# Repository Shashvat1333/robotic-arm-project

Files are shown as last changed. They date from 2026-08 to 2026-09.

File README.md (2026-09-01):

# Robotic Arm Project

A custom-designed, multi-axis robotic arm controlled wirelessly via Bluetooth using an ESP32 and Bluepad32.

Robotic Arm Render

## Table of Contents
- [Overview](#overview)
- [Repository Structure](#repository-structure)
- [CAD Model & Assembly](#cad-model--assembly)
- [Schematic & Wiring](#schematic--wiring)
- [Firmware](#firmware)
- [Getting Started](#getting-started)
- [Bill of Materials (BOM)](#bill-of-materials-bom)
- [License](#license)

## Overview
This project combines mechanical engineering, 3D printing, electronics design, and embedded firmware development into a cohesive hardware system. The primary goal is to build a fully articulated, functional robotic arm with multiple degrees of freedom that responds seamlessly to a wireless game controller. By integrating custom gear assemblies, iterative 3D-printed brackets, and robust power management, this project bridges the gap between digital design and physical prototyping.

Building a robotic arm from scratch meant handling every stage of development personally. From sketching the initial motion paths to balancing structural weight limits against servo torque ratings, every choice was made to keep the system sturdy yet responsive. Instead of relying on pre-made kits, the entire assembly was built up component by component to ensure it could handle real physical loads without flexing or slipping at the joints.

### Key Features:
- **Custom Mechanical Design:** Engineered with precise tolerance margins for 3D printing, featuring custom gear trains and linkage assemblies designed in Onshape.
- **Wireless Control Integration:** Utilizes an ESP32 microcontroller paired with the Bluepad32 framework to read live joystick and button inputs from a standard Bluetooth controller.
- **Safe Power Distribution:** Employs a dedicated 5V 10A DC power supply routed through custom soldered bus lines on a perfboard, replacing high-resistance plastic breadboards to handle heavy servo current draws safely.

---

## Repository Structure

```
robotic-arm-project/
├── CAD/                   # .step files for all printed/machined parts
├── Firmware/               # ESP32 firmware (FIRMWARE.ino)
├── Wiring Diagrams.md      # Full wiring/schematic reference
├── Images & Demo/          # Renders, build photos, demo video
├── BOM.md                  # Full bill of materials
├── JOURNAL.md              # Build log / engineering journal
├── LICENSE.md
└── README.md
```

---

## CAD Model & Assembly
The structural framework and mechanical joints of the robotic arm were modeled with close attention to mechanical clearances and structural integrity. Designing the parts in Onshape allowed for careful testing of gear ratios, pivot points, and clearance gaps so the 3D-printed pieces fit together smoothly with minimal post-processing. To support open-source collaboration and manufacturing, all production-ready parts and full assemblies are stored directly in the [CAD](https://github.com/Shashvat1333/robotic-arm-project/tree/main/CAD) folder as `.step` files.

When putting the physical frame together, thermal-set inserts were melted directly into the plastic structures using a soldering iron, giving the M3 bolts a solid metal thread to bite into. This prevents the plastic from stripping out under regular movement and makes it easy to take joints apart for maintenance or upgrades.

https://github.com/user-attachments/assets/6f530a01-1f68-40d2-a437-52708d4fa79e

---

## Schematic & Wiring
Because this project utilizes modular components wired together on a custom soldered perfboard rather than a manufactured printed circuit board, the system relies on a detailed wiring layout. High-torque servos pull significant current under load, which is why standard breadboards were abandoned early on to prevent melting rails or voltage drops.

Instead, a custom perfboard layout uses heavy solder traces to act as main power and ground distribution rails, ensuring every servo gets clean, steady voltage directly from the 10-amp adapter. You can view the complete connection specifications and documentation in [Wiring Diagrams.md](Wiring%20Diagrams.md).

| Component | ESP32 GPIO (Signal) | Power (+) | Ground (–) |
|---|---|---|---|
| Servo 1 – Base (DS3225MG) | GPIO 13 | Perfboard + bus line | Perfboard – bus line |
| Servo 2 – Shoulder (DS3225MG) | GPIO 12 | Perfboard + bus line | Perfboard – bus line |
| Servo 3 – Elbow (DS3225MG) | GPIO 14 | Perfboard + bus line | Perfboard – bus line |
| Servo 4 – Wrist Pitch (DS3225MG) | GPIO 27 | Perfboard + bus line | Perfboard – bus line |
| Servo 5 – Wrist Roll (MG90S) | GPIO 26 | Perfboard + bus line | Perfboard – bus line |
| Servo 6 – Gripper (MG90S) | GPIO 25 | Perfboard + bus line | Perfboard – bus line |
| ESP32 NodeMCU Board | — | VIN pin connected to + bus | GND pin connected to – bus |
| Power Supply | — | 5V 10A DC Adapter (+) | 5V 10A DC Adapter (–) |

---

## Firmware
The control firmware is written in C++ using the Arduino framework, integrating the `ESP32Servo` and `Bluepad32` libraries to map controller joysticks and triggers directly to servo positions. The program continuously listens for a paired Bluetooth gamepad, reads the analog stick coordinates, and translates those inputs into precise PWM signals for each servo motor.

- **Source code:** [FIRMWARE.ino](https://github.com/Shashvat1333/robotic-arm-project/blob/main/FIRMWARE.ino)
- **Required libraries:** `ESP32Servo`, `Bluepad32`
- **Board:** ESP32 Dev Module

---

## Getting Started

To build and run this project yourself:

1. **Print the parts** — Slice the `.step` files from the [CAD](https://github.com/Shashvat1333/robotic-arm-project/tree/main/CAD) folder (built and tested using PLA+ filament).
2. **Assemble the frame** — Install M3 heat-set inserts into the printed parts using a soldering iron, then bolt the assembly together following the CAD model.
3. **Wire the electronics** — Follow [Wiring Diagrams.md](Wiring%20Diagrams.md) to connect servos, the ESP32, and the power supply through the perfboard bus lines.
4. **Flash the firmware** — Open [FIRMWARE.ino](https://github.com/Shashvat1333/robotic-arm-project/blob/main/FIRMWARE.ino) in the Arduino IDE, install the `ESP32Servo` and `Bluepad32` libraries, select the **ESP32 Dev Module** board, and upload.
5. **Pair a controller** — Power on the arm and pair a Bluetooth gamepad. The arm will respond to joystick and button input once connected.

---

## Bill of Materials (BOM)

| # | Item | Qty | Description | Price (tax incl.) | Link |
|---|---|-----|---|---|---|
| 1 | 25KG Digital RC Servo (DS3225) | 4 Pack | Waterproof, high-torque servo for main arm joints | $65.60 | [AliExpress](https://www.aliexpress.com/item/1005009734701047.html) |
| 2 | MG90S 9g Micro Servo Motor | 2 Pack | Small servo for gripper / wrist actuation | $7.40 | [AliExpress](https://www.aliexpress.com/item/4000903254039.html) |
| 3 | 5V 10A Power Supply Adapter | 1 | Main power supply for servos | $23.40 | [AliExpress](https://www.aliexpress.com/item/1005004121728138.html) |
| 4 | 5.5x2.1mm DC Power Female Jack Pigtail | 1 | Connects power adapter to circuit | $6.00 | [AliExpress](https://www.aliexpress.com/item/1005008401380227.html) |
| 5 | ESP32-WROOM-32 Dev Board (CH340C, Type-C) | 1 | Dual-core WiFi + Bluetooth MCU for arm control (Bluepad32) | $8.00 | [AliExpress](https://www.aliexpress.com/item/1005008981904299.html) |
| 6 | 22AWG Stranded Wire | 1 | Flexible wiring for all connections, including servo leads | $10.17 | [AliExpress](https://www.aliexpress.com/item/1005006441248773.html) |
| 7 | KADRICK 420PCS M3 Heat Set Inserts Kit | 1 | Threaded inserts for 3D-printed parts | $25.48 | [Amazon](https://www.amazon.com/Threaded-Assortment-M3x6-30mm-Installation-Printing/dp/B0GYRQG7F2/) |
| 8 | Perfboard (6cm × 8cm) | 1 | Solder-based board — replaces breadboard for safe high-current servo wiring | $2.80 | [AliExpress](https://www.aliexpress.com/item/1005006829112244.html) |
| 9 | PLA+ Filament 1.75mm 1KG | 673g used | 3D printing material for arm structural parts — cost reflects grams actually used (sliced in PrusaSlicer), not full spool purchased | $15.07 | [AliExpress](https://www.aliexpress.com/item/1005011683191901.html) |
| 10 | Import Charges | — | Customs/import fees on international orders | $12.00 | — |

**Total Project Cost: $175.92**

Full breakdown also available in [BOM.md](https://github.com/Shashvat1333/robotic-arm-project/blob/main/BOM.md).

---

## License

This project is licensed under the terms specified in [LICENSE.md](https://github.com/Shashvat1333/robotic-arm-project/blob/main/LICENSE.md).

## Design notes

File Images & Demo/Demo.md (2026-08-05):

Robotic Arm Project DEMOs
-------------------------------------------------------------------------------------------------------------------------------------------------------------------

https://github.com/user-attachments/assets/6f530a01-1f68-40d2-a437-52708d4fa79e

-------------------------------------------------------------------------------------------------------------------------------------------------------------------

Main Arm

-------------------------------------------------------------------------------------------------------------------------------------------------------------------

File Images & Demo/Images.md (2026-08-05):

Robotic Arm Project Images
-------------------------------------------------------------------------------------------------------------------------------------------------------------------



-------------------------------------------------------------------------------------------------------------------------------------------------------------------



-------------------------------------------------------------------------------------------------------------------------------------------------------------------



-------------------------------------------------------------------------------------------------------------------------------------------------------------------



-------------------------------------------------------------------------------------------------------------------------------------------------------------------



-------------------------------------------------------------------------------------------------------------------------------------------------------------------



-------------------------------------------------------------------------------------------------------------------------------------------------------------------



-------------------------------------------------------------------------------------------------------------------------------------------------------------------



-------------------------------------------------------------------------------------------------------------------------------------------------------------------



-------------------------------------------------------------------------------------------------------------------------------------------------------------------



-------------------------------------------------------------------------------------------------------------------------------------------------------------------



-------------------------------------------------------------------------------------------------------------------------------------------------------------------

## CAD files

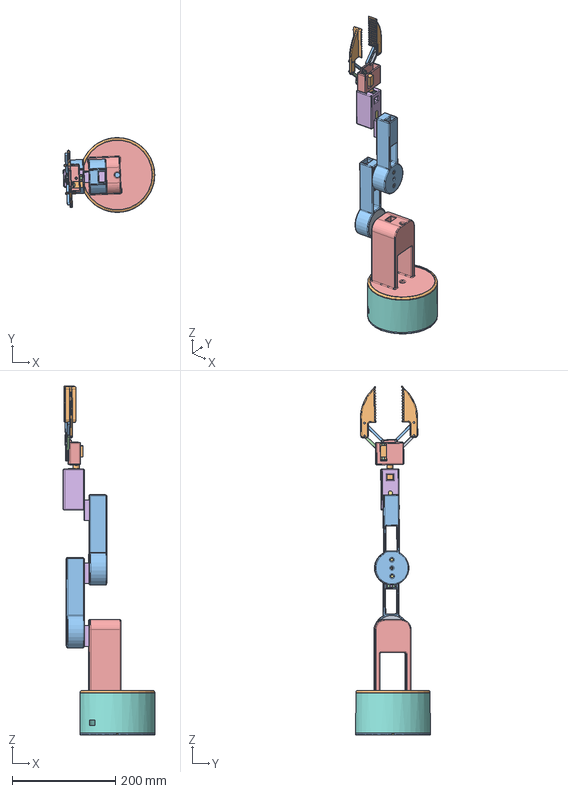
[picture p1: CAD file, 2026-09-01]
CAD/MAIN.step
177.9 x 145.4 x 676.5 mm
Spur gear (24 teeth)
Spur gear (20 teeth) x 2

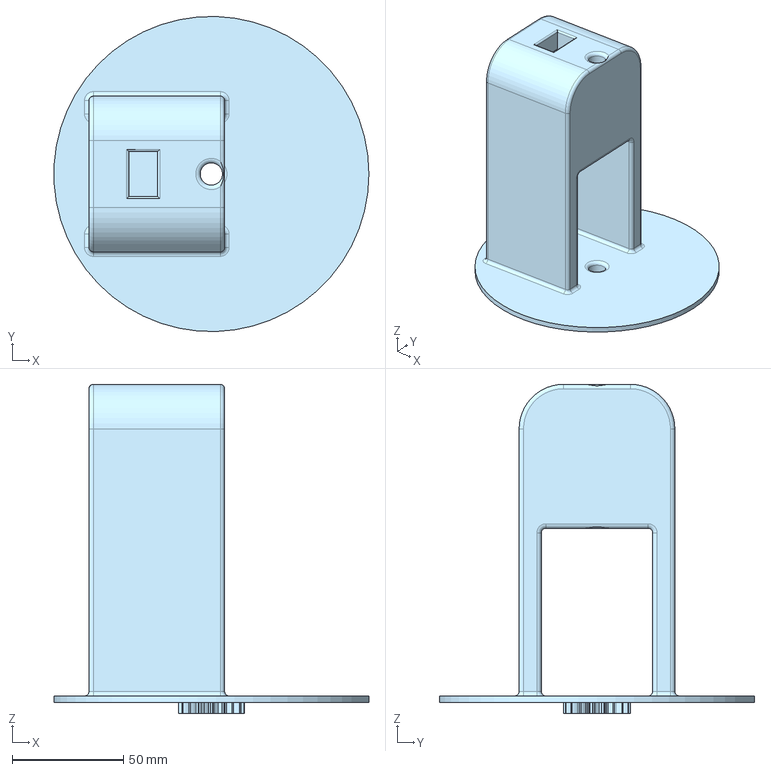
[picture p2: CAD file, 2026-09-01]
CAD/Base Top-Sholder.step
141.5 x 141.5 x 148.0 mm

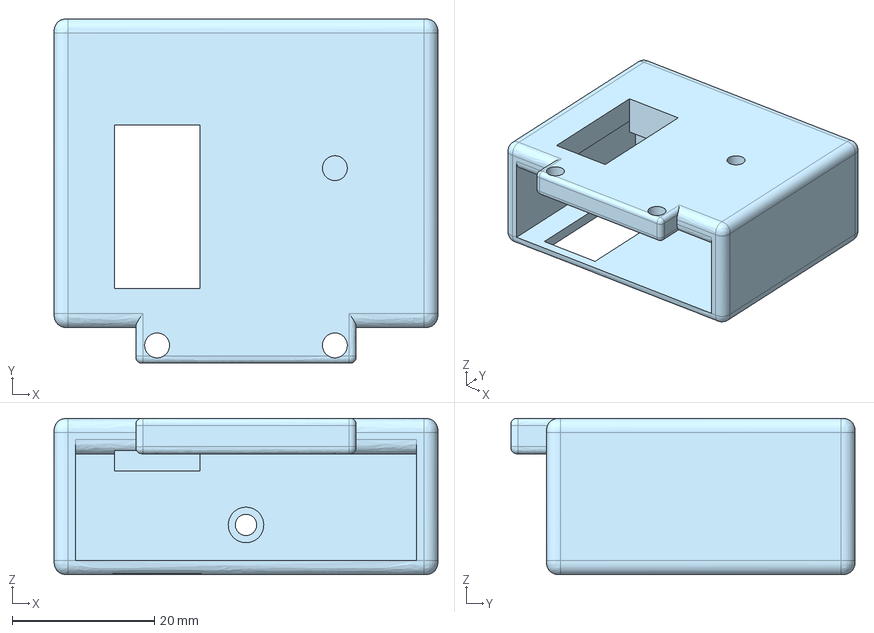
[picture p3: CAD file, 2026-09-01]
CAD/Claw Base.step
54.0 x 48.4 x 22.0 mm

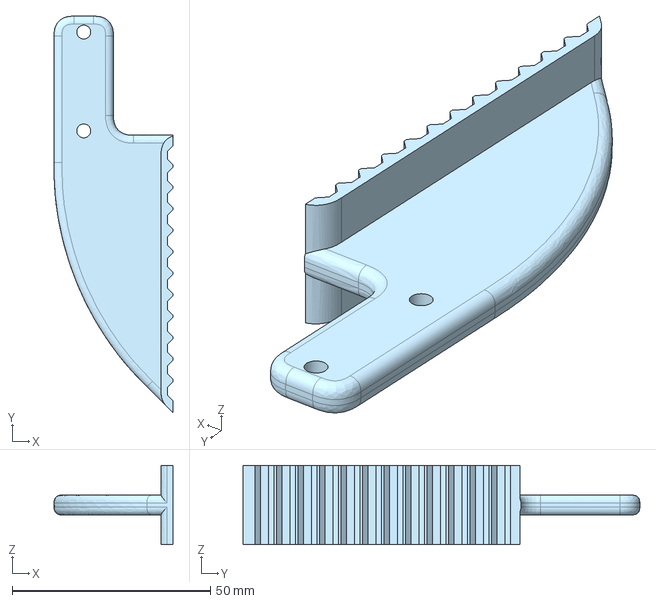
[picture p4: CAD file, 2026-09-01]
CAD/Claw x2.step
30.0 x 100.0 x 20.0 mm

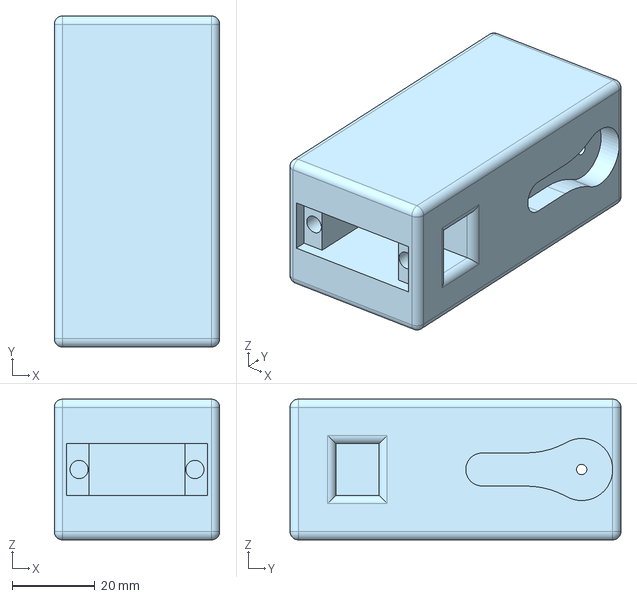
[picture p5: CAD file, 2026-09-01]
CAD/Wrist.step
40.0 x 80.0 x 34.0 mm

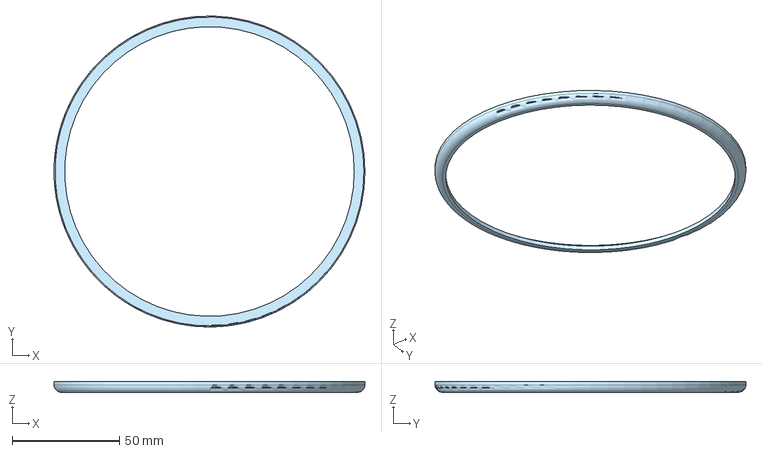
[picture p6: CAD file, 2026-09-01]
CAD/retaining ring.step
145.0 x 145.0 x 5.00 mm

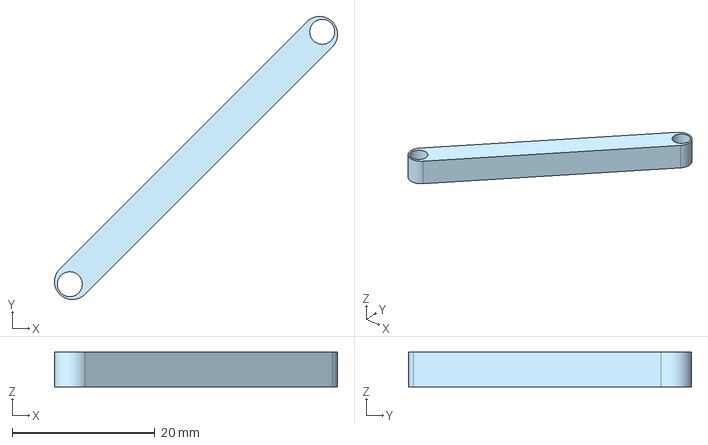
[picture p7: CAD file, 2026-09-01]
CAD/Base to Claw connector x2.step
39.6 x 39.6 x 4.90 mm

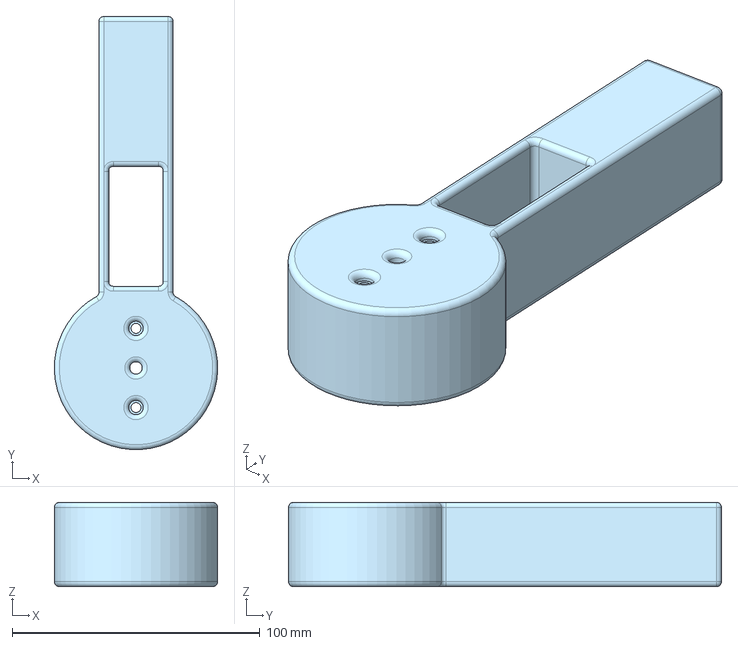
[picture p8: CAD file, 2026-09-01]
CAD/Arm x2.step
65.9 x 174.9 x 34.0 mm

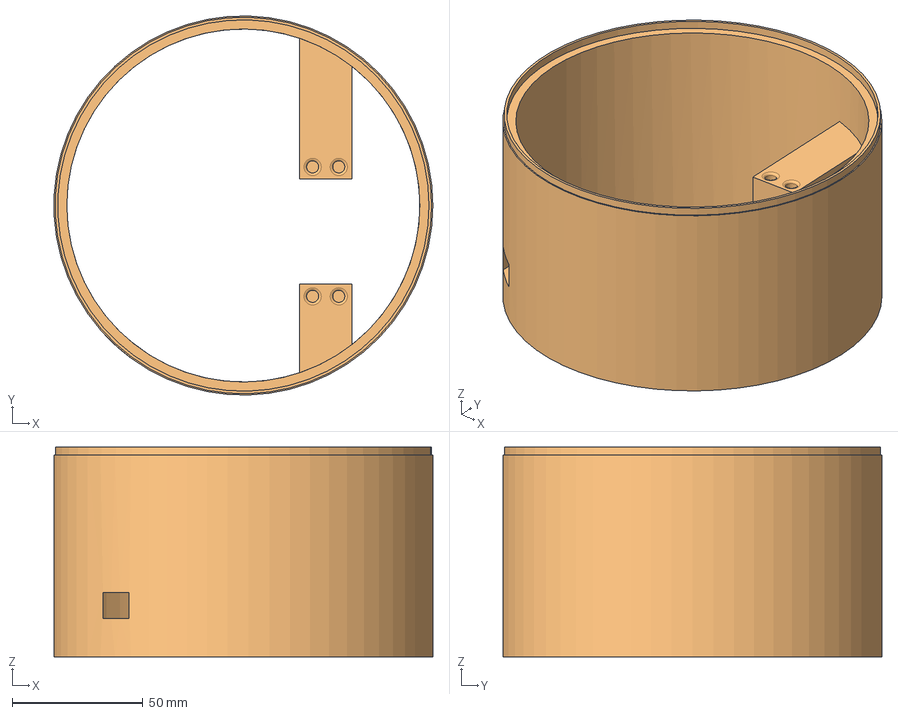
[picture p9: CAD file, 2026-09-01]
CAD/Base Body.step
144.9 x 144.9 x 80.3 mm

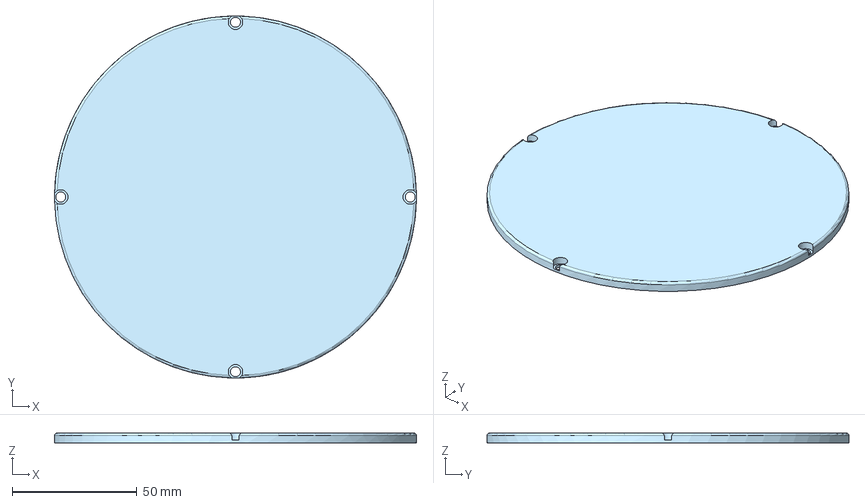
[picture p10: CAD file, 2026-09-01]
CAD/Base Bottom.step
145.0 x 145.0 x 4.00 mm

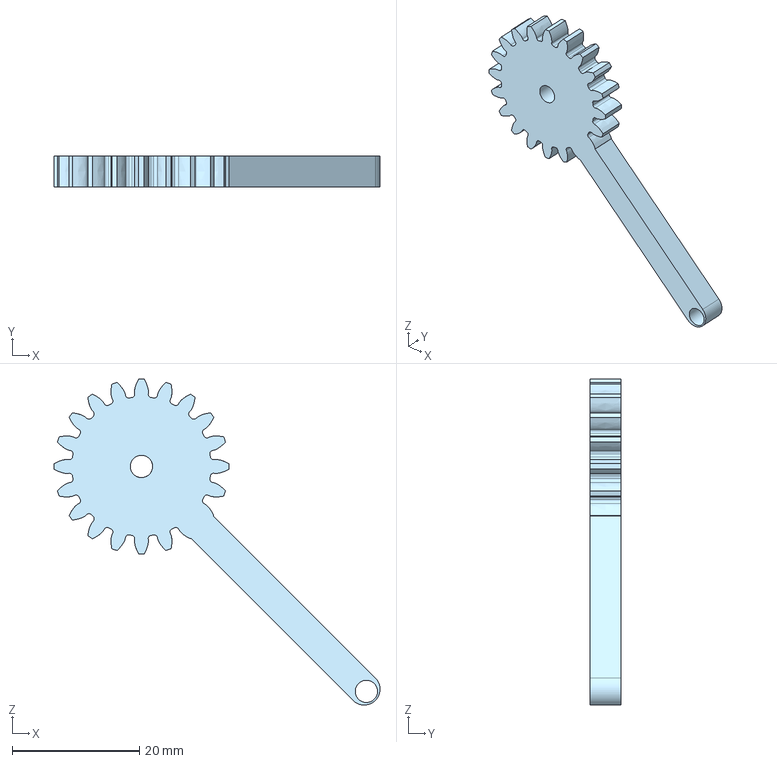
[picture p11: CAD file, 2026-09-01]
CAD/Claw Gear.step
51.2 x 4.90 x 51.2 mm

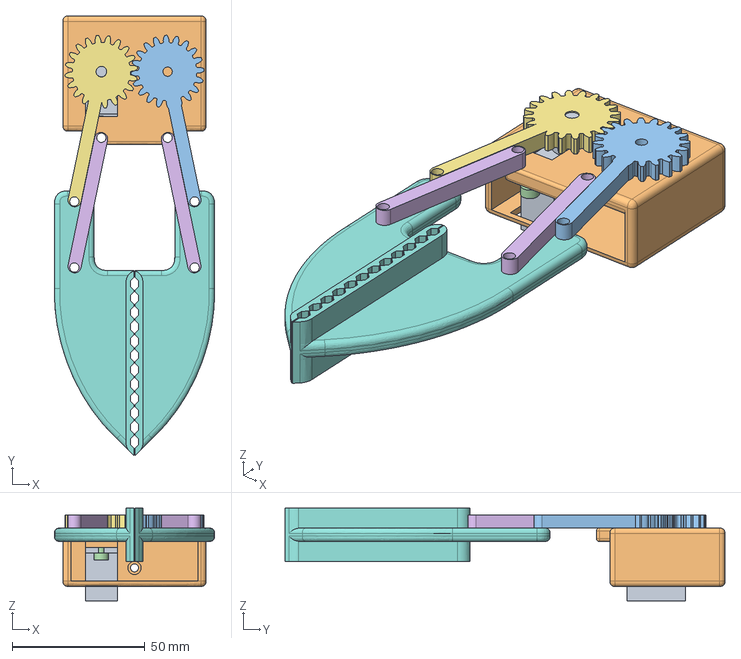
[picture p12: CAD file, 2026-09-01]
CAD/CLAW.step
60.4 x 166.0 x 34.9 mm
Spur gear (20 teeth) x 2

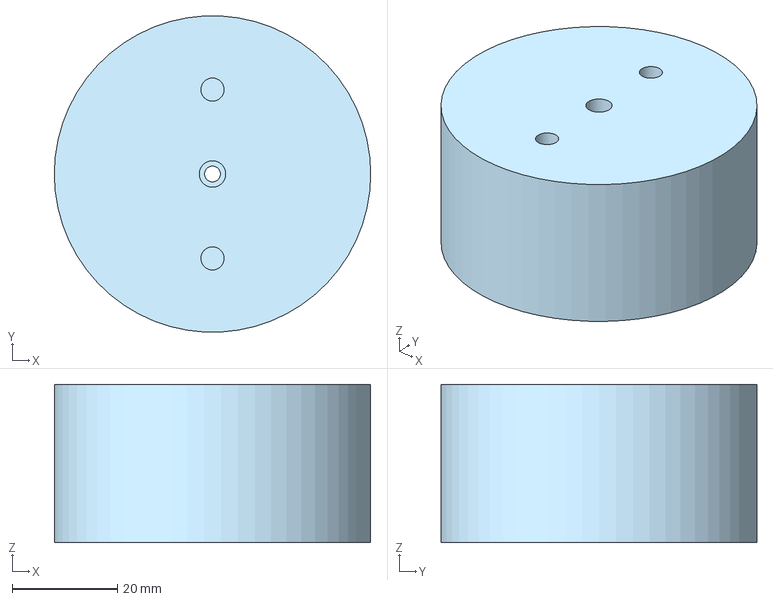
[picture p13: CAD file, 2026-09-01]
CAD/Arm-Servo Connector x2.step
60.0 x 59.9 x 30.0 mm

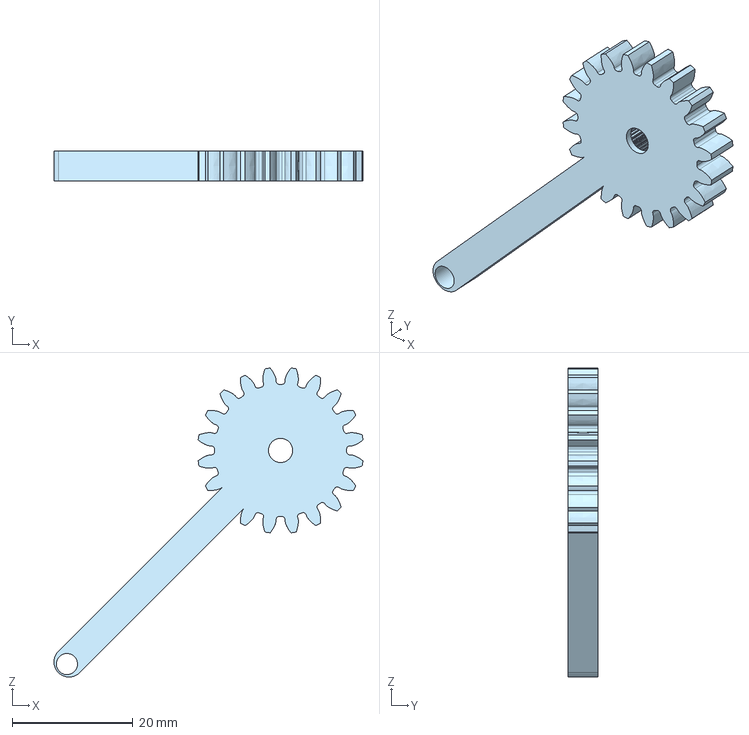
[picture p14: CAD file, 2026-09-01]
CAD/Claw Gear Servo.step
51.1 x 5.00 x 51.1 mm

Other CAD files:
CAD/Servo Gear.step

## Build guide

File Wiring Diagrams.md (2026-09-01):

**Robotics Arm Servo Wiring Diagram**
------------------------------------------------------------------------



------------------------------------------------------------------------

| Component | ESP32 GPIO (Signal) | Power (+) | Ground (–) |
| --- | --- | --- | --- |
| Servo 1 – Base (DS3225MG) | GPIO 13 | Perfboard + line | Perfboard – line |
| Servo 2 – Shoulder (DS3225MG) | GPIO 12 | Perfboard + line | Perfboard – line |
| Servo 3 – Elbow (DS3225MG) | GPIO 14 | Perfboard + line | Perfboard – line |
| Servo 4 – Wrist Pitch (DS3225MG) | GPIO 27 | Perfboard + line | Perfboard – line |
| Servo 5 – Wrist Roll (MG90S) | GPIO 26 | Perfboard + line | Perfboard – line |
| Servo 6 – Gripper (MG90S) | GPIO 25 | Perfboard + line | Perfboard – line |
| ESP32 (board power, via fuse) | — | Perfboard + line → ESP32 5V/VIN pin | Perfboard – line → ESP32 GND pin |
| Perfboard + power line | — | 5V 10A Adapter (+) | — |
| Perfboard – ground line | — | — | 5V 10A Adapter (–) |

**How it flows:** The 5V 10A DC power supply connects directly to the custom soldered vertical bus lines on the perfboard, creating solid positive and negative rails. Every servo taps its power and ground straight into these soldered tracks. The ESP32 also bridges directly to these shared rails for its supply voltage and common ground, while individual signal wires run straight from each servo to their respective ESP32 GPIO pins.

------------------------------------------------------------------------

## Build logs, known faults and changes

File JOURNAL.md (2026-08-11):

Robotic Arm Project Journal
-------------------------------------------------------------------------------------------------------------------------------------------------------------------

**Day 1**: July 11, 2026

Time spent: **2 hours**

Started planning the robotic arm today, mostly research before touching CAD. Compared 3, 4, 5, and 6 DOF designs, and I'm currently leaning toward 6 DOF since it gives more flexibility, even though it adds complexity. Looked into open-loop vs closed-loop servos and decided open-loop PWM should be fine since my payload is under 500g. Also learned torque needs go up the closer a joint is to the base, so I'm planning stronger servos like the MG996R for the base and shoulder and weaker ones like the MG90S for the wrist and gripper. Picked the ESP32 over Arduino mainly because of the built-in WiFi.
Next: build a BOM, calculate real torque numbers, start early CAD sketches.

-------------------------------------------------------------------------------------------------------------------------------------------------------------------

**Day 2**: July 12, 2026

Time spent: **2.5 hours**

Ran actual torque numbers today. With a 42cm arm and 100g payload, the shoulder needs about 15.4 kg cm of torque, which is more than a standard MG996R can handle comfortably. Switched the base and shoulder servos to the DS3230MG since it gives a lot more headroom. Updated my planned lineup to two DS3230MG for base and shoulder, two MG996R for elbow and wrist pitch, and two MG90S for wrist roll and gripper. Also bumped my power supply up to 5V 10A after realizing worst-case current draw could hit 9 to 13A.
Next: finish the BOM, design brackets for the heat set inserts, check clearances before printing anything.

-------------------------------------------------------------------------------------------------------------------------------------------------------------------

**Day 3**: July 13, 2026

Time spent: **4 hours 30 minutes**

Started actual CAD today, focused mostly on the base gear system. I wanted full 360 rotation out of a 270-degree servo instead of adding a slip ring, and worked out that a 3 to 4 step up gear ratio would do it. My first gear sizes were too small, and the teeth interfered with each other, so I bumped them up to 18 and 24 teeth using the same ratio, and that fixed it. Learned a lot about using Onshape's gear tools and Revolute Mates to get the assembly moving correctly. Also planning to pad the center distance slightly to account for printing tolerances.
Next: finish the base gear housing, print and test the gear pair, then move on to the shoulder.

-------------------------------------------------------------------------------------------------------------------------------------------------------------------

**Day 4**: July 14, 2026

Time spent: **3 hours**

Spent today researching print tolerances to get the base and shoulder parts ready for actual printing. CAD for the shoulder and base parts is now roughly 75% complete. Looked into clearance rules for press fit and moving parts, and figured out proper hole sizing for the M3 heat set inserts. Also researched how to install the inserts properly with a soldering iron without making a mess around them. Settled on doing dimensional adjustments directly in CAD instead of relying on the slicer, and picked print settings for the smaller detailed parts.
Next: finish the base and shoulder parts completely.

-------------------------------------------------------------------------------------------------------------------------------------------------------------------

**Day 5**: July 15, 2026

Time spent: **2 hours**

Finished the base and shoulder components and started building the full assembly to see how everything actually fits together. Caught a small mistake where my insert hole size was slightly off from the manufacturer spec and fixed it. Seeing everything together made it a lot easier to spot interference issues that weren't obvious when parts were designed separately. Added some fillets and reinforced a few areas that looked like they'd crack under load.
Next: keep building the assembly, check remaining parts for weak spots, finish the rest of the CAD.



-------------------------------------------------------------------------------------------------------------------------------------------------------------------

**Day 6**: July 16, 2026

Time spent: **5 hours**

Finished the shoulder arm and made some strength improvements to the base and shoulder parts. Decided to use standard 25T servo arms instead of designing custom connectors, so I made quick models of the DS3230MG and a 25T arm to check the fit in the assembly. Found the actual manufacturer mounting dimensions for the servo, which should make future brackets a lot more accurate.
Next: keep adding parts to the assembly and keep designing the rest of the arm.



-------------------------------------------------------------------------------------------------------------------------------------------------------------------

**Day 7**: July 17, 2026

Time spent: **1.5 hours**

Made more changes to the shoulder base and arm and kept building out the assembly. Nothing too dramatic today, mostly just confirming everything still fits properly once I could see it all together. Reminded me again that catching problems in CAD is a lot easier than catching them after printing.
Next: finish the remaining CAD parts and confirm the full assembly fits.



-------------------------------------------------------------------------------------------------------------------------------------------------------------------

**Day 8**: July 18, 2026

Time spent: **1 hour**

Swapped the remaining MG996R servos for the DS3225MG since it gives roughly double the torque for less money and is waterproof with metal gears. Turns out the mounting pattern is basically the same, so I didn't need to redesign any brackets. Also trimmed some unnecessary material out of low-stress arm segments to save filament. Assembly is around 80% done now.
Next: keep building out the rest of the assembly and clean up the arm CAD.



-------------------------------------------------------------------------------------------------------------------------------------------------------------------

**Day 9**: July 19, 2026

Time spent: **4 hours**

Finished the wrist section today and spent a good amount of time comparing gripper designs, still deciding between a few options. Found out dimension sheets for the same part can vary a lot between sellers, so I can't just trust one source. Went back through some older CAD parts and found details I'd missed earlier. Also ran into a weird gear meshing issue in the base where everything checked out on paper but the gears still interfered at certain angles, so I'm testing a slightly wider center distance to fix it.
Next: confirm the wider center distance works, finalize the gripper design, keep reviewing older parts.



-------------------------------------------------------------------------------------------------------------------------------------------------------------------

**Day 10**: July 20, 2026

Time spent: **2 hours 25 minutes**

Locked in the parallel jaw gripper design and spent most of the day figuring out where to put the servo inside the housing and designing the gear mechanism that turns the servo rotation into the jaw movement. Servo placement mattered a lot more than I expected, get it wrong and there's no room for the gears or the jaws can't move properly.
Next: finish the gripper CAD, check that the drive gears mesh correctly, test the servo placement. 




-------------------------------------------------------------------------------------------------------------------------------------------------------------------

**Day 11**: July 21, 2026

Time spent: **4 hours**

Finished the gripper mechanism today using a gear-driven parallelogram linkage so the jaws stay parallel while opening and closing. Spent most of the time fighting the gear problems from earlier and learned that correct meshing depends on rotational alignment too, not just size. Fixed it by offsetting the gears by half a tooth pitch. Also found what looked like an alignment problem was actually just a center distance that was slightly too small. One more issue came from over-constraining the linkage, removing an extra constraint let it move freely on its own.
Next: fix remaining issues, finish the full arm assembly, keep testing the gripper's range of motion.

https://github.com/user-attachments/assets/6f530a01-1f68-40d2-a437-52708d4fa79e

-------------------------------------------------------------------------------------------------------------------------------------------------------------------

**Day 12**: July 22, 2026

Time spent: **2 hours**

Finished troubleshooting and completed the full CAD assembly today, base, shoulder, elbow, wrist, and gripper all working together. Testing everything as one system made it much easier to see how changes in one part affected the rest. No major redesigns needed at this point, so I'm shifting into verification mode.
Next: do a final review of every part against real hardware specs and finish the BOM.



-------------------------------------------------------------------------------------------------------------------------------------------------------------------

**Day 13**: July 23, 2026

Time spent: **3 hours**

Reviewed every CAD part looking for mistakes and fixed what I found. Worked out wire routing, leaving extra slack at each joint so the servos can move freely without pinching anything. Tried exporting the assembly to PyBullet and ran into a wall, it detected zero degrees of freedom, meaning none of my mates were recognized as actual joints. Also found some parts were missing material properties.
Next: fix the assembly mates, assign material properties, and try exporting again.



-------------------------------------------------------------------------------------------------------------------------------------------------------------------

**Day 14**: July 24, 2026

Time spent: **2.5 hours**

Wanted to make an animation of the arm moving so I could see how the joints work together before building the real thing, thought it would be quick but it wasn't. Tried the PyBullet route again and hit the same issues as before. Ended up using Onshape's Gear Relation feature instead to link the joints together so one driving joint animates the whole arm at once. Good enough to demo the motion for now.
Next: keep improving the joint definitions, finish the remaining CAD, start pricing out the parts list.

Main Arm

-------------------------------------------------------------------------------------------------------------------------------------------------------------------

**Day 15**: July 26, 2026

Time spent: **2 hours 30 minutes**

Finalized the BOM today and went through every component to make sure nothing was missing. Swapped some Amazon.com parts for Amazon.ca ones to save on shipping and import costs. Added a fuse holder to protect the ESP32 that I'd missed before. Learned some cheap MG servos only have metal gears on part of the gearbox, the rest is plastic, which is fine for this build but good to know for later. Total estimated cost came out to around $257.10 CAD.
Next: make final CAD tweaks, apply for the grant, start the physical build once parts arrive.



-------------------------------------------------------------------------------------------------------------------------------------------------------------------

**Day 16**: July 27, 2026

Time spent: **1 hour 47 min**

Added real M3 screw and heat set insert models into the assembly instead of just leaving the mounting holes empty. Makes the whole thing look and feel more real, and it's genuinely useful, putting the hardware models in exposed a few clearance and fit issues I hadn't noticed before. Fixed those before printing.
Next: apply for the Stardance grant once the form's back up, order parts once budget's confirmed, start the physical build.



-------------------------------------------------------------------------------------------------------------------------------------------------------------------

**Day 17**: August 8, 2026

Time spent: **2 hours**

Started learning how to wire and code servos using an ESP32 on Cirkit today. The end goal is using the Bluepad32 library to connect a gaming controller and control the arm with it, but decided to start simple first with push buttons controlling the servos instead of jumping straight into wireless input. Got one servo moving properly which confirmed the basic wiring and code logic works. Ran into a wiring issue with the other servos that I couldn't figure out today, so that's the first thing to fix next session. Also landed on which specific library I'll be using going forward. Learned a good amount about the different ESP32 pin types and what they're for, along with the coding structure needed to control servos properly.
Next: fix the wiring issue on the circuit, then start learning how to control the servos with Bluepad32 and a gaming controller.



-------------------------------------------------------------------------------------------------------------------------------------------------------------------

**Day 18**: August 9, 2026

Time spent: **3 hours**

Fixed the button issue from last session today. Turned out it was just a wiring mix up where the connections weren't matched up correctly. Traced through the circuit, fixed the wiring, and the servos started responding properly. Also spent time learning the Bluepad32 library and wrote code to let an Xbox controller's joysticks and buttons control the servos directly. Expected it to be pretty complicated going in, but once I actually got into it, it was a lot more straightforward than it looked. Ran into a handful of setup and communication issues early on but worked through them one by one. By the end of the session I had the full code done for controlling the servos with the Xbox controller.
Next: order the parts and start 3D printing once funding is approved.

https://github.com/user-attachments/assets/10d47a55-776d-477c-bda6-7a32d190e0bc

-------------------------------------------------------------------------------------------------------------------------------------------------------------------

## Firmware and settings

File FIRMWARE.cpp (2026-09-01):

#include <ESP32Servo.h>
#include <Bluepad32.h>

Servo Servo1;
Servo Servo2;
Servo Servo3;
Servo Servo4;
Servo Servo5;
Servo Servo6;

ControllerPtr Controller;

int WristRotationAngle = 90;
int ClawAngle = 90;

void Connected(ControllerPtr ctl){
  Controller = ctl;
}

void Disconnected(ControllerPtr ctl){
  Controller = nullptr;
}

void setup() {
  Servo1.attach(21, 500, 2500);
  Servo2.attach(5, 500, 2500);
  Servo3.attach(18, 500, 2500);
  Servo4.attach(19, 500, 2500);
  Servo5.attach(4);
  Servo6.attach(22);

  BP32.setup(&Connected, &Disconnected);
  BP32.forgetBluetoothKeys();
}

void loop() {
  BP32.update();

  if(Controller && Controller->isConnected()){

    int BaseAngle = map(Controller->axisX(), -512, 512, 0, 270);
    Servo1.write(BaseAngle);

    int SholderAngle = map(Controller->axisY(), -512, 512, 0, 270);
    Servo2.write(SholderAngle);

    int ElbowAngle = map(Controller->axisRY(), -512, 512, 0, 270);
    Servo3.write(ElbowAngle);

    int WristAngle = map(Controller->axisRX(), -512, 512, 0, 270);
    Servo4.write(WristAngle);

 
    if(Controller->a()){
      WristRotationAngle++;
    }
    if(Controller->b()){
      WristRotationAngle--;
    }
    WristRotationAngle = constrain(WristRotationAngle, 0, 180);
    Servo5.write(WristRotationAngle);

    if(Controller->y()){
      ClawAngle++;
    }
    if(Controller->x()){
      ClawAngle--;
    }
    ClawAngle = constrain(ClawAngle, 0, 180);
    Servo6.write(ClawAngle);
    
    delay(15); 
  }
}

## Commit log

2026-07-12 Add Day 2 journal entry for robotic arm project
    Documented Day 2 progress on robotic arm project, including torque calculations, servo selection, and power supply updates.
2026-07-13 Add Day 3 journal entry for robotic arm design
    Documented progress on CAD design for robotic arm, including gear system calculations and adjustments for 3D printing tolerances.
2026-07-15 Document Day 5 progress on CAD design
    Continued CAD design for robotic arm, focusing on base and shoulder components. Adjusted insert hole diameter and reinforced design for strength.
2026-07-17 Update JOURNAL.md with Day 6 entry
    Added Day 6 journal entry detailing CAD design progress and decisions made.
2026-07-17 Add Day 7 entry for CAD design progress
    Documented progress on CAD design for robotic arm, including time spent, lessons learned, decisions made, and next steps.
2026-07-18 Add Day 8 entry on CAD design and servo updates
    Documented progress on CAD design and servo selection for the robotic arm project. Updated decisions and next steps based on material optimization and component specifications.
2026-07-19 Update JOURNAL.md with Day 6 progress
    Documented progress on robotic arm design, including CAD updates, research on gripper designs, and troubleshooting gear meshing issues.
2026-07-21 Add Day 10 entry for gripper design progress
    Documented the progress and design decisions for Day 10 of the robotic arm project, focusing on the gripper design and mechanism.
2026-07-22 Add Day 11 entry on gripper mechanism design
    Documented Day 11 progress on robotic arm project, detailing design, learning, decisions, and next steps.
2026-07-23 Add Day 12 entry with robotic arm assembly details
    Documented progress on Day 12, including assembly verification and next steps.
2026-07-24 Document Day 13 activities and insights
    Added details for Day 13, including work done on robotic arm design, lessons learned, decisions made, and next steps for simulation preparation.
2026-07-25 Add Day 14 journal entry on robotic arm animation
    Documented the work done on robotic arm animation, including challenges faced and solutions implemented using Onshape's Gear Relation feature.
2026-07-26 Create Robot Arm Parts Checklist
    Added a checklist for robot arm parts with links and prices.
2026-07-26 Revise prices and total in CHECKLIST.md
    Updated checklist with new prices and import charges.
2026-07-26 Document Day 15 progress on robotic arm project
    Finalized bill of materials for the robotic arm project, including a safety component and verified all major components. Updated parts to reduce shipping costs and estimated total project cost.
2026-07-27 Update JOURNAL.md with Day 16 progress
    Continued improving the robotic arm CAD assembly by adding realistic mechanical details, including M3 screws and brass heat-set inserts. Fixed design issues and confirmed that current improvements are sufficient without major redesign.
2026-08-03 Finalize CAD assembly and bill of materials
    Completed the full CAD assembly of the robotic arm, ensuring all components fit together correctly and function as intended. Finalized the bill of materials, confirmed all major components, and made adjustments for clearance and fit issues before printing.
2026-08-05 Add images for Robotic Arm project
    Added multiple images related to the Robotic Arm project.
2026-08-05 Revise project journal with daily updates
    Updated project journal with daily progress and details on design decisions for the robotic arm project, including torque calculations, CAD progress, and BOM finalization.
2026-08-05 Add project journal for robotic arm development
    Documented the progress of the robotic arm project over 16 days, detailing time spent, tasks completed, and next steps for each day.
2026-08-05 Revise project journal with images and updates
    Updated project journal to reflect images and progress for each day of the robotic arm project, including details on design changes, assembly, and component selection.
2026-08-05 Add demo information to Demo.md
    Added demo section with links and images for the Robotic Arm Project.
2026-08-11 Update JOURNAL.md with Days 17 and 18 entries
    Documented progress on learning to wire and code servos using ESP32, including issues faced and solutions implemented. Outlined next steps for the project.
2026-08-14 Fix formatting and update prices in BOM.md
2026-08-15 Fix link and price for RC Servo in BOM
    Updated the link for the 4-Pack 25KG Digital RC Servo Waterproof DS3225 and adjusted the price.
2026-08-15 Fix link for 4-Pack 25KG Digital RC Servo
    Updated the link for the 4-Pack 25KG Digital RC Servo Waterproof DS3225.
2026-08-15 Fix link formatting for servo item in BOM
    Updated link formatting for the 4-Pack Digital RC Servo.
2026-08-15 Fix link formatting for servo item in BOM
2026-08-15 Fix link formatting in BOM.md
2026-08-21 Revise BOM format and update item details
    Updated the Bill of Materials for the robotics arm, adding a detailed table format and adjusting item descriptions and prices.
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2026-08-21 Update total amount format in BOM.md
    Removed currency specification from total amount.
2026-08-21 Modify BOM header and price column format
    Updated BOM to remove currency specification and adjusted price column header.
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2026-08-21 Update Wiring Diagrams with component connections
    Added detailed wiring information for servos and ESP32.
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2026-08-27 Update link for 25KG Digital RC Servo
    Updated the link for the 25KG Digital RC Servo (DS3225) to an AliExpress URL.
2026-08-27 Revise BOM with updated prices and sources
    Updated prices and links for various items in the Bill of Materials. Changed some items from Amazon to AliExpress for better pricing.
2026-08-27 Update link for 25KG Digital RC Servo in BOM
    Updated the link for the 25KG Digital RC Servo (DS3225) in the BOM.
2026-08-27 Update price and link for 25KG Digital RC Servo
    Updated the price and link for the 25KG Digital RC Servo.
2026-08-27 Update import charges in BOM.md
    Updated the import charges for international orders from $12.00 to $22.00.
2026-08-27 Adjust import charges and total in BOM.md
    Updated import charges and total cost in BOM.
2026-09-01 Rename Arm x2.stl to Arm x2.step
    [Arm x2.step, Arm x2.stl]
2026-09-01 Revise wiring diagram for servo connections
    Updated wiring diagram details to reflect changes from breadboard to perfboard connections and clarified power flow description.
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2026-09-01 Fix missing semicolon in delay function
    [FIRMWARE.ino]
2026-09-01 Add README for Robotic Arm Project
    Added detailed project documentation for the robotic arm, including features, CAD models, schematics, firmware, and a bill of materials.
2026-09-01 Revise README2 with detailed project overview and BOM
    Updated project overview and features for clarity and detail. Enhanced BOM with itemized costs and links.
2026-09-01 Fix CAD Assembly image link in README2.md
    Updated the CAD Assembly image link in README2.md.
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
